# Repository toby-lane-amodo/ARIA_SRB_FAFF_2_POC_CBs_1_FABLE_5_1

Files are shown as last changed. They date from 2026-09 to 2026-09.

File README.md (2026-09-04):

# ARIA_SRB_FAFF_2_POC_CBs_1

Electronics for **FAFF 2** — a linear actuator with force feedback, built as an OEM-style
module for soft-material characterisation. `CBs_1` is the proof-of-concept control board.

A BLDC turns a 5 mm/rev ball screw. A load cell between the screw and an interchangeable probe
tip measures applied force; a magnetic linear encoder measures displacement directly. An
STM32H723 closes a force or displacement control loop and streams force and position to a host
over USB at up to 4800 SPS.

Two build variants, differing only in maximum force: **V50N** (± 50 N) and **V10N** (± 10 N).

> **This board is deliberately larger than the final product.** It is a development-board-style
> build that precedes miniaturisation, so that every block can be brought up and measured
> independently. See [`docs/TEST_PLAN.md`](docs/TEST_PLAN.md).

## Status

**Schematic complete and integrated**, first review pass applied. All nine blocks are drawn,
the root sheet is wired, and the design is internally consistent: 398 components, 251 nets,
101 sheet pins, **0 ERC errors and 0 warnings** at `--severity-all` with nothing suppressed.
Every component has a footprint that resolves.

Review the KiCad files themselves — there is no PDF and none is generated (`DEC-0028`).
The open points to be ruled on are in
[`hardware/kicad/faff2_cbs1/SCHEMATIC_REVIEW_LOG.md`](hardware/kicad/faff2_cbs1/SCHEMATIC_REVIEW_LOG.md),
round 1. **PCB layout is the next wave**; no board file exists yet.

## Repository map

```
README.md                        this file
AGENTS.md                        conventions every session needs
docs/
  REQUIREMENTS.md                numbered requirements, traceable to the spec, both variants
  ARCHITECTURE.md                block architecture, MCU resource allocation, open gaps
  DECISIONS.md                   every judgement call, dated, with reasoning
  TEST_PLAN.md                   test points, isolation, current breaks, bring-up order
  FAFF-2-Electronics-Full.svg    THE block diagram (authoritative architecture)
  HardwareDesignStandard_DRAFT/  captain's in-house EEE design standard (verbatim draft)
  decisions/                     one record per schematic task, incl. actuator-sch-integrate.md
  review/                        the schematic review pack PDF (regenerate, never hand-edit)
hardware/
  kicad/faff2_cbs1/              the KiCad 9 project - see below
  cubemx/                        the STM32CubeMX .ioc - THE MCU pin-map authority
tools/                           re-runnable generators for the root sheet and the DRV8323S land
datasheets/                      collected datasheets (see its README for the shopping list)
```

## The KiCad project

`hardware/kicad/faff2_cbs1/faff2_cbs1.kicad_pro` — **KiCad 9 only** (DEC-0017).

| Sheet | Block |
|---|---|
| `faff2_cbs1.kicad_sch` | root - the block map, wired: 101 sheet pins (DEC-0022) |
| `power_entry_24v.kicad_sch` | 24 V in on KPJX-4S, protection |
| `power_rails.kicad_sch` | 24 V → 5 V / 3V3 / analog rails |
| `mcu.kicad_sch` | STM32H723VET6, USB3320 ULPI PHY, USB-C, QSPI RAM |
| `motor_drive.kicad_sch` | DRV8323 + FETs, current sense, motor + encoder connectors |
| `loadcell_afe.kicad_sch` | ADS1235 bridge ADC, 5 V excitation |
| `linear_encoder.kicad_sch` | RS-422 receiver, Bogen IKP11 header |
| `temp_sense.kicad_sch` | ADS1120, two RTD/NTC probe channels |
| `nvm_calibration.kicad_sch` | I2C EEPROM for calibration data |
| `ui_io.kicad_sch` | buttons, LEDs, SMA SYNC out, limit switches |

The `mcu` sheet is **A2**; every other sheet is A3. There is no `test_debug` sheet — test
coverage lives on the circuit page it covers, so the SWD + USART3 debug header, the rail probe
header and the GND hooks are blocks H, J and K on `mcu`
([`docs/decisions/actuator-rev-testdebug.md`](docs/decisions/actuator-rev-testdebug.md)).

**One block per file, one owner per file.** See `AGENTS.md`.

### Setting up the Amodo library (required before opening the project)

The project's `sym-lib-table` and `fp-lib-table` reference the house library through path
variables. Set **both**, in KiCad → *Preferences* → *Configure Paths*:

| Variable | Windows (captain's KiCad) | WSL / Linux |
|---|---|---|
| `AMODO_KICAD_LIB` | `C:\Amodo\AmodoKiCadLib` | `/mnt/c/Amodo/AmodoKiCadLib` |
| `AMODO_3D` | `C:\Amodo\AmodoKiCadLib\3D` | `/mnt/c/Amodo/AmodoKiCadLib/3D` |

`AMODO_3D` is needed separately because the Amodo footprints already reference their 3D models
through it. Without these the symbols and footprints will not resolve. See DEC-0015.

### Checking the schematic

```sh
AMODO_KICAD_LIB=/mnt/c/Amodo/AmodoKiCadLib \
  kicad-cli sch erc --severity-all --exit-code-violations \
  -o /tmp/erc.rpt hardware/kicad/faff2_cbs1/faff2_cbs1.kicad_sch
```

Currently **0 errors, 0 warnings**, with no severity suppressed (DEC-0021). Keep it that way.

## Source documents

The project document store lives in Notion, at
**TERN - University of Cambridge / ARIA_SRB_FAFF_2 / ARIA_SRB_FAFF_2 Document Store**:

| Document | Role |
|---|---|
| *Project Specification Document* | **The requirements authority.** `docs/REQUIREMENTS.md` consolidates it; where they disagree, Notion wins |
| *ARIA_SRB_FAFF_2_CBs_1 Design Log* | Electronics decisions and part selection rationale |
| *ARIA_SRB_FAFF_2_CBs_1 Block Diagram* | Excalidraw source of `docs/FAFF-2-Electronics-Full.svg` |
| *ARIA_SRB_FAFF_2 Handover Document* | Project handover |
| Specification Design Log | How the spec numbers were derived |

Also referenced: the Google Sheet **FAFF 2 EEE Prelim Calc** (force/noise budget, BLDC sizing,
power budget) and **FAFF2 Plan and Budget** (work-package phasing).

## Key parts

STM32H723VET6 · DRV8323 gate driver · USB3320 ULPI PHY · TI ADS1235 bridge ADC · TI ADS1120
temperature ADC · HBK S2M load cell (10 N / 50 N) · Bogen IKP11 magnetic linear encoder ·
KPJX-4S power connector. BLDC deliberately not fixed (DEC-0004).

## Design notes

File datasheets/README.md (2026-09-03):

# Datasheets

Collect datasheets for the parts below as blocks are designed. Keep the manufacturer's own PDF
where possible, named `<MPN>.pdf`.

Note that KiCad symbols must carry a **working web URL** in their Datasheet field (pressing `d`
in KiCad opens it) — these local copies are for offline reference, not a substitute.

## Collected

| File | Part | Block | Revision |
|---|---|---|---|
| `250721_IKP11_technical_data_sheet.pdf` | Bogen IKP11 | `linear_encoder` | rev 3.7, 2025-07-21 (supersedes the rev linked below) |
| `LMR51610.pdf` | TI LMR51606/LMR51610 buck | `power_rails` | SLUSEY1B, Dec 2023 - added for the `U301` swap, review round 1 batch 2 |
| `ADPL42005.pdf` | ADI ADPL42005 LDO | `power_rails` | Rev. 0, 2024 - added for the `U302`/`U303` swap, review round 3. **Mirror copy** (datasheetall.com): analog.com times out from the build environment. Same Rev. 0 document; re-fetch from analog.com when a machine can reach it |

## Fixed parts

✅ = collected, see above.

| Part | Block | Notes |
|---|---|---|
| STM32H723VET6 | `mcu` | LQFP100. Datasheet + RM0468 reference manual. CPN `STM32H723VET6TR` |
| USB3320 | `mcu` | USB 2.0 ULPI transceiver |
| DRV8323 | `motor_drive` | 3-phase gate driver, SPI variant, 3 integrated current-sense amplifiers |
| TI ADS1235 | `loadcell_afe` | 24-bit bridge ADC. **Symbol already exists in `Amodo_ADCs.kicad_sym`** |
| TI ADS1120 | `temp_sense` | 16-bit ADC with PGA and IDACs, for RTD/NTC |
| HBK S2M | `loadcell_afe` | Load cell, 10 N and 50 N variants. Datasheet + wiring diagram (4- and 6-wire) |
| Bogen IKP11 ✅ | `linear_encoder` | `IKP11-Z1.4-P1-V5-D1-R0.5-F1000-C1`. Local: `250721_IKP11_technical_data_sheet.pdf` (rev 3.7). Web: [technical data sheet](https://www.bogen-magnetics.com/media/450/t-file/240802_IKP11_technical_data_sheet-1.pdf) — note that URL serves the older 2024-08-02 revision |
| Bogen LMS-I1-L70-W5-A03-K | (mechanical) | Magnetic scale, adhesive backed, ±3 µm accuracy class |
| KPJX-4S | `power_entry_24v` | Latching circular power connector, 4-way |

## To be selected

| Part | Block | Notes |
|---|---|---|
| QSPI RAM / memory | `mcu` | For force profiles, on OCTOSPI1 in quad mode |
| I2C EEPROM | `nvm_calibration` | Calibration and compensation data |
| Power FETs (×6) | `motor_drive` | 24 V, sized around 1.229 A phase working point |
| Rail regulators | `power_rails` | Set undecided — see OQ-02 |
| RS-422 receiver | `linear_encoder` | 3 channels (A/B/Z), 5 V in → 3V3 logic out |
| Temperature probes (×2) | `temp_sense` | RTD or NTC — see OQ-04 |
| USB-C receptacle, SMA jack | `mcu`, `ui_io` | |
| ESD protection devices | interfaces | USB-C, SMA, encoder, limit switch inputs |

## Explicitly NOT needed

**USB-PD / CYPD-class controllers.** FAFF 1 used a CYPD3177-class part; FAFF 2 has a dedicated
24 V supply and the USB-C port carries data only. Do not collect these. See DEC-0001, DEC-0002.

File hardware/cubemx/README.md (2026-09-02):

# CubeMX

`ARIA_SRB_FAFF_2_POC_CBs_1.ioc` is the STM32CubeMX starting point from the captain, and is
**the authority for the MCU part and every MCU-side pin assignment and net name** (DEC-0013).
Pin allocations are quoted in `docs/ARCHITECTURE.md §3.2` so you need not open CubeMX to
draw a block; if a block needs a pin that is not there, change the `.ioc` first and re-commit it.

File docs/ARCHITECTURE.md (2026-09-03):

# FAFF 2 CBs_1 - Electronics Architecture

The electronics block architecture for the `ARIA_SRB_FAFF_2` proof-of-concept control board,
as evidenced by the specification, the block diagram, the CBs_1 electronics design log, the
preliminary calculations, and the CubeMX starting point.

**Read `docs/REQUIREMENTS.md` first.** Requirement IDs (`REQ-*`) and decision IDs (`DEC-*`,
`OQ-*`) referenced here are defined there and in `docs/DECISIONS.md`.

## 1. Authorities

| Rank | Artefact | Authority over |
|---|---|---|
| 1 | Notion *Project Specification Document* | All requirements. |
| 2 | `docs/FAFF-2-Electronics-Full.svg` | Block-level architecture: which blocks exist and how they interconnect. |
| 3 | `hardware/cubemx/ARIA_SRB_FAFF_2_POC_CBs_1.ioc` | The MCU part and every MCU-side pin assignment and net name. |
| 4 | Notion *CBs_1 Design Log* | Part selections and their rationale. |
| 5 | `faff2-eee-prelim-calc.md` (Google Sheet extract) | The numbers behind the spec. |

The predecessor `ARIA_FAFF_CBs_1-block-diagram-v0.1.drawio` (FAFF 1) is **superseded** and is
reference only. FAFF 1 used a stepper motor, USB-PD power negotiation (CYPD3177-class), a
barrel-jack alternate input and a power-OR stage. **None of those are in FAFF 2** - see DEC-0001
and DEC-0002.

## 2. System context

A linear actuator for soft-material characterisation. A BLDC turns a 5 mm/rev ball screw; a
load cell between the screw and an interchangeable probe tip measures applied force; a magnetic
linear encoder measures displacement directly. The board closes a force or displacement control
loop and streams force and position to a host over USB.

Off-board, on the actuator (`BD`: "Linear Actuator Mech Parts"): the BLDC and its rotary
encoder/Hall sensors, the IKP11 read head and its magnetic scale, and the HBK S2M load cell.
Everything else is on CBs_1.

Control rates: ADC sampling 4800 SPS, closed-loop force bandwidth 40 Hz spec (48 Hz by the
calculation's 100:1 sample ratio), host stream decimated to 150 SPS. `REQ-ME-06`, `REQ-CC-03`.

## 3. Block architecture

```
                                                          [ off-board, on the actuator ]
  KPJX-4S 24 V ──▶ power_entry_24v ──▶ power_rails ──▶ (all blocks)
                         │ V24_MON            │
                         │                    │ +24V_SW
                         ▼                    ▼
                        mcu ◀──────────── motor_drive ──▶ J-MOT ─▶ BLDC
                   STM32H723VET6      DRV8323 + 6 FETs
                         │            phase I, VBUS, FET temp
                         │            ◀── J-MENC ── rotary encoder A/B/I + Halls
                         │
     ┌───────────────────┼────────────────────┬───────────────┬──────────────┐
     │ SPI3              │ TIM5               │ SPI2          │ I2C1         │ GPIO/TIM15
     ▼                   ▼                    ▼               ▼              ▼
 loadcell_afe      linear_encoder        temp_sense     nvm_calibration    ui_io
   ADS1235          RS-422 rx             ADS1120         EEPROM        buttons, LEDs,
     │                  │                     │                          SMA SYNC,
     ▼                  ▼                     ▼                          limit switches
  J-LC ─▶ S2M      J-ENC ─▶ IKP11      J-T1 (load cell)                       │
                                       J-T2 (encoder rail mid)                │ LIMIT_nBRK
                                                                              ▼
     mcu also carries: USB3320 ULPI PHY ──▶ USB-C (data only)          TIM1 BREAK
                       OCTOSPI1 quad ──▶ force-profile RAM             (motor kill)
                       SWD + USART3 ──▶ debug header (on the mcu sheet)
```

### 3.1 Block responsibilities

| Sheet file | Block | Responsibility | Chief evidence |
|---|---|---|---|
| `power_entry_24v.kicad_sch` | Power entry | 24 V in on KPJX-4S; protection, fusing, inrush, TVS, filtering; `V24_MON` divider | REQ-EL-01..04 |
| `power_rails.kicad_sch` | Power rails | +24V_SW → +5V, +3V3, analog rail(s) + reference; per-rail isolation links and current breaks | REQ-EL-02/03, CALC power budget |
| `mcu.kicad_sch` | Controller | STM32H723VET6, clocks, reset, boot, SWD; USB3320 ULPI PHY + USB-C; OCTOSPI1 quad RAM | REQ-AR-01/12/13/16 |
| `motor_drive.kicad_sch` | Motor drive | DRV8323 + 6 FETs, phase current sense, DC-link sense, FET temp, motor + rotary-encoder connectors | REQ-AR-02..06 |
| `loadcell_afe.kicad_sch` | Load cell AFE | ADS1235 bridge ADC, 5 V excitation, 4-/6-wire load cell interface | REQ-FF-08..13, REQ-AR-08/09 |
| `linear_encoder.kicad_sch` | Linear encoder | RS-422 A/B/Z receiver → 3V3, IKP11 header, 5 V read-head supply | REQ-PS-05..09, REQ-AR-07 |
| `temp_sense.kicad_sch` | Temperature | ADS1120 + two RTD/NTC probe channels | REQ-EL-07, REQ-AR-10 |
| `nvm_calibration.kicad_sch` | NVM | I2C1 EEPROM for calibration and compensation data | REQ-EL-08, REQ-AR-11 |
| `ui_io.kicad_sch` | User I/O | Buttons, LEDs, SMA SYNC out, limit switch inputs incl. the hardware brake path | REQ-EL-05/06/09, REQ-CC-06, REQ-SF-01/05 |

Nine sheets, not ten. **Test coverage lives on the circuit page it covers**, so there is no
`test_debug` sheet: the SWD + USART3 debug header (`REQ-AR-15`), the consolidated rail probe
header and the GND hooks for scope clips are blocks **H**, **J** and **K** on `mcu.kicad_sch`,
alongside the crystal that gives the USB PHY its own 24 MHz reference (block **C**).
See `docs/decisions/actuator-rev-testdebug.md`.

### 3.2 MCU resource allocation

From the `.ioc` — the authority. Quoted here so block workers need not open CubeMX.

**Motor drive (TIM1, ADC1/2, SPI2)**
| Net | Pin | Function |
|---|---|---|
| `MOTOR_PWM_AH/AL` | PE9 / PE8 | TIM1_CH1 / CH1N |
| `MOTOR_PWM_BH/BL` | PE11 / PE10 | TIM1_CH2 / CH2N |
| `MOTOR_PWM_CH/CL` | PE13 / PE12 | TIM1_CH3 / CH3N |
| `DRV8323_nFAULT` | PE15 | TIM1_BKIN - hardware trip |
| `LIMIT_nBRK` | PE6 | TIM1_BKIN2 - hardware trip |
| `MOTOR_I_A/B/C` | PA6 / PC4 / PA7 | ADC INP3 / INP4 / INP7 |
| `MOTOR_FETTEMP` | PA4 | ADC INP18 |
| `VBUS_MON` | PC5 | ADC INP8 (see OQ-01) |
| `DRV8323_EN/CAL/nCS` | PD10 / PD5 / PD7 | GPIO out |
| `MOTOR_ENCODER_A/B/I` | PC6 / PC7 / PC8 | TIM3 CH1 / CH2 / CH3 |
| `HALL1/2/3` | PE14 / PD14 / PD15 | GPIO in |

**Load cell AFE (SPI3)**
| Net | Pin | Function |
|---|---|---|
| `ADS1235_SCLK/MISO/MOSI` | PC10 / PC11 / PD6 | SPI3 |
| `ADS1235_nCS` | PA15 | SPI3_NSS (hardware NSS) |
| `ADS1235_nDRDY` | PD1 | EXTI1 |
| `ADS1235_START` | PC12 | GPIO out |
| `ADS1235_nRESET` | PD0 | GPIO out |
| `ADS1235_CLKIN` | PC9 | RCC_MCO2 - ADC master clock |

**Linear encoder (TIM5)**: `LINEAR_ENCODER_A/B/Z` = PA0 / PA1 / PA2. TIM5 encoder mode TI12 on
A/B; CH3 input capture on Z.

**Shared config bus (SPI2, "CONFIG_SPI")**: `CONFIG_SPI_SCK` PA9, `CONFIG_SPI_MISO` PB14,
`CONFIG_SPI_MOSI` PB15. Chip selects: `DRV8323_nCS` PD7, `ADS1120_nCS` PD3.
**Three blocks share this bus** - see §5.

**NVM (I2C1)**: `EEPROM_SCL` PB8, `EEPROM_SDA` PB9.

**Force-profile RAM (OCTOSPI1, quad)**: `QSPI_P1_CLK` PB2, `QSPI_P1_nCS` PB6,
`QSPI_P1_IO0..IO3` PD11 / PD12 / PE2 / PD13.

**USB (USB_OTG_HS, ULPI, device HS)**: `ULPI_D0..D7` = PA3, PB0, PB1, PB10, PB11, PB12, PB13,
PB5; `ULPI_CK` PA5; `ULPI_STP` PC0; `ULPI_DIR` PC2_C; `ULPI_NXT` PC3_C;
`USB3320_nRESET` PE4.

**User I/O**: `BTN_1/2` PE0 / PE1; `LED_1/2` PA12 / PA11; `SYNC_TRIG` PE5 (TIM15_CH1);
`LIM_A` PD2 (EXTI2), `LIM_B` PD4 (EXTI4).

**Debug**: SWDIO PA13, SWCLK PA14, SWO PB3; `DBG_TX` PD8, `DBG_RX` PD9 (USART3).

**Clock**: `PH0-OSC_IN` in *HSE external clock source* mode. `PH1-OSC_OUT` is **not**
allocated, so the HSE input must be a driven clock, not a bare crystal (OQ-03). CubeMX
currently shows PLL source HSI and SYSCLK 64 MHz - that is the untouched CubeMX default, not a
designed clock tree, and it will change.

77 of 100 pins are allocated. Spare pins exist for the gaps in §6.

## 4. Power architecture

24 V enters on the KPJX-4S latching circular connector (REQ-EL-04). There is **no USB-PD, no
bus power and no alternate barrel-jack input** - all three were FAFF 1 features (DEC-0001,
DEC-0002). USB-C carries USB 2.0 data only.

Budget: 5.185 W quiescent, 25 W peak (REQ-EL-03), 7 W typical at a static 50 N hold
(REQ-EL-02). The 5 V rail feeds bridge excitation and the IKP11 read head; 3V3 feeds the MCU,
USB3320, DRV8323 logic, QSPI and EEPROM; the ADS1235 and ADS1120 need a quiet analog rail and
reference.

**Awaiting evidence.** The block diagram is signal-architecture only and shows **no power
blocks at all**. Rail count, topology (switcher vs LDO), sequencing and the analog-rail
strategy are therefore **not** externally specified - they are OQ-02, to be decided by the
`power_rails` task and recorded in `DECISIONS.md`.

## 5. Cross-block concerns

Things no single block owns. A block worker who changes one of these must say so.

1. **SPI2 is shared** by `motor_drive` (DRV8323), `temp_sense` (ADS1120) and, by proximity,
   any future config peripheral. Bus loading, series termination and the stub topology are a
   joint concern. Chip selects are per-peripheral, so only the three bus wires are shared.
2. **The TIM1 BREAK path is safety-critical.** Two independent sources trip it: `DRV8323_nFAULT`
   (PE15, BKIN) from `motor_drive`, and `LIMIT_nBRK` (PE6, BKIN2) from `ui_io`. Neither block
   may change the polarity or the drive type of its break net unilaterally. REQ-SF-05/06.
3. **Analog ground and reference strategy** spans `power_rails`, `loadcell_afe` and
   `temp_sense`. The 40 nV-scale signals of the load cell path (SLOG) set the bar.
4. **Motor FET temperature** (`MOTOR_FETTEMP`, PA4, internal ADC) belongs to `motor_drive`, not
   to `temp_sense`. `temp_sense` owns only the two ADS1120 precision channels of REQ-EL-07.
   DEC-0011.
5. **Test points and isolation links** follow the producer-owns-the-break rule: whichever block
   generates a rail or signal owns its test point, isolation link and current break. DEC-0007.

## 6. What is still awaiting evidence

Facts this architecture does **not** yet fix, and what would fix them.

| Gap | Blocked on | Tracked as |
|---|---|---|
| Rail set, topology, sequencing, analog-rail strategy | Block diagram is signal-only; needs a design decision | OQ-02 |
| HSE external clock source | `mcu` task decision, possibly shared with USB3320 | OQ-03 |
| `VBUS_MON` allocation (motor DC-link vs USB VBUS) | Captain confirmation | OQ-01 |
| Temperature probe type (RTD vs NTC) | `temp_sense` task decision | OQ-04 |
| EEPROM `nWP`, rail PGOOD/enable pins | No `.ioc` pins allocated; may need an `.ioc` revision | OQ-06, OQ-07 |
| Per-variant current-limit implementation | `motor_drive` task decision | OQ-08 |
| Root-sheet interconnect wiring | Child sheets must declare hierarchical labels first | DEC-0009 |
| BLDC part number | Deliberately open - all candidates share this design | DEC-0004 |
| Load cell 4-wire vs 6-wire build | Support both; 6-wire is the accuracy option | DEC-0014 |

## 7. Superseded FAFF 1 features

For reviewers who know the predecessor. Do not carry these across.

| FAFF 1 | FAFF 2 | Why |
|---|---|---|
| Stepper motor drive | BLDC, DRV8323 + FETs | Stepper resonances and gearbox poles; BLDC pole separation pushes resonances far higher (SLOG) |
| USB-PD controller (CYPD3177-class) | None | Dedicated 24 V supply; USB is data only (REQ-EL-10) |
| Barrel jack alternate input + power OR | Single KPJX-4S 24 V input | REQ-EL-04 |
| STM32H7 (unspecified) | STM32H723VET6, pinned | `.ioc` (DEC-0013) |
| Renishaw ATOM DX linear encoder | Bogen IKP11, RS-422 | 34-week ATOM DX lead time (DEC-0003) |

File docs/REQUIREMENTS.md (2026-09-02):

# FAFF 2 CBs_1 - Consolidated Requirements

Consolidated, numbered requirements for the **ARIA_SRB_FAFF_2** proof-of-concept control
board (`CBs_1`). Every requirement traces to a source; values are quoted verbatim from the
source, including both design variants.

**Authority.** The Notion *Project Specification Document* is the requirements authority.
Where this file and Notion disagree, Notion wins and this file is a defect.

| Tag | Source |
|---|---|
| `SPEC` | Notion, *ARIA_SRB_FAFF_2 Document Store / Project Specification Document* |
| `ELOG` | Notion, *ARIA_SRB_FAFF_2_CBs_1 Design Log* |
| `SLOG` | Notion, *Specification Design Log* |
| `CALC` | Google Sheet *FAFF 2 EEE Prelim Calc* (extract `faff2-eee-prelim-calc.md`) |
| `BD` | `docs/FAFF-2-Electronics-Full.svg` - FAFF 2 electronics block diagram |
| `IOC`  | `hardware/cubemx/ARIA_SRB_FAFF_2_POC_CBs_1.ioc` - STM32 pin-map authority |

**Variants.** Two build variants differing only in maximum force: **V50N** (± 50 N) and
**V10N** (± 10 N). `SPEC §2.3`.

Status key: **B** = binding on CBs_1 electronics; **C** = context (mechanical/firmware, drives
electronics indirectly); **O** = open, see [Open Questions](#open-questions).

---

## 1. Mechanical context (`REQ-ME-*`)

Not electronics deliverables, but they set the electrical operating point.

| ID | Requirement | V50N | V10N | Unit | Source | St |
|---|---|---|---|---|---|---|
| REQ-ME-01 | Displacement range | 40 | 40 | mm | SPEC §3 | C |
| REQ-ME-02 | Continuous force | ± 50 | ± 10 | N | SPEC §3 | C |
| REQ-ME-03 | Maximum actuation speed | 20 | 20 | mm/s | SPEC §3 | C |
| REQ-ME-04 | Max cycle speed (low), force control | 10 | 10 | cycles/min | SPEC §3 | C |
| REQ-ME-05 | Max cycle speed (fast), force control | 60 | 60 | cycles/min | SPEC §3 | C |
| REQ-ME-06 | Force control loop bandwidth (small signal) | 40 | 40 | Hz | SPEC §3 | B |
| REQ-ME-07 | Probe tip interchangeable, threaded socket | — | — | — | SPEC §3 | C |
| REQ-ME-08 | Ball screw lead | 5 | 5 | mm/rev | SPEC assumptions, CALC | C |

Notes on REQ-ME-04/05: 1 % max force over/undershoot (% of commanded step amplitude),
amplitude < 4 mm pk-pk at 10 cyc/min; 5 % and amplitude < 6 mm pk-pk at 60 cyc/min. `SPEC §3`.

## 2. Force feedback (`REQ-FF-*`)

| ID | Requirement | V50N | V10N | Unit | Source | St |
|---|---|---|---|---|---|---|
| REQ-FF-01 | Sensing method: load cell | Load cell | Load cell | — | SPEC §4 | B |
| REQ-FF-02 | Force measurement range | ± 50 | ± 10 | N | SPEC §4 | B |
| REQ-FF-03 | Force accuracy | 60 | 12 | mN | SPEC §4 | B |
| REQ-FF-04 | Force noise, 4800 SPS raw | < 20 | < 5 | mN pk-pk | SPEC §4 | B |
| REQ-FF-05 | Force noise, 150 SPS decimated | < 2.5 | < 0.5 | mN pk-pk | SPEC §4 | B |
| REQ-FF-06 | Force resolution, 4800 SPS raw | 2 | 0.5 | mN | SPEC §4 | B |
| REQ-FF-07 | Force resolution, 150 SPS decimated | 1 | 0.2 | mN | SPEC §4 | B |
| REQ-FF-08 | Load cell: HBK S2M, accuracy class 0.02 | — | — | — | SPEC assumptions, SLOG | B |
| REQ-FF-09 | Load cell sensitivity | 2 | 2 | mV/V | SPEC §"Force" | B |
| REQ-FF-10 | Bridge excitation voltage | 5 | 5 | V | SPEC §"Force" | B |
| REQ-FF-11 | Full-scale bridge output swing | ± 10 | ± 10 | mV | SPEC §"Force" | B |
| REQ-FF-12 | Bridge ADC: ADS1235, gain 128, 4800 SPS Sinc2 | — | — | — | CALC, ELOG, BD | B |
| REQ-FF-13 | Load cell connection: 4-wire **or** 6-wire | — | — | — | BD ("4 or 6 wire") | B |

REQ-FF-03 note (SPEC §4): "All stream rates. Dominated by load cell systematics. Averaging
does not improve accuracy. Accuracy valid at 20 ± 2 °C."

Supporting calculation (`CALC`, Force sheet), for traceability only - not itself a requirement:
input sensitivity 0.2 mV/N (V50N) / 1.0 mV/N (V10N); ADS1235 input noise 2.40 µV pk-pk at
4800 SPS Sinc2 = 12.0 / 2.4 mN pk-pk, giving 167 % / 208 % headroom against REQ-FF-04.
ADS1235 FSR 78.125 mV at gain 128 / VREF 5 V; 18-bit conservative depth gives 1.49 / 0.30 mN
ADC resolution (134 % / 168 % headroom against REQ-FF-06). Streamed output 150 SPS,
2.12 / 0.42 mN pk-pk against the 2.5 / 0.5 mN of REQ-FF-05.

## 3. Position sensing (`REQ-PS-*`)

Single specification, both variants. `SPEC §5`.

| ID | Requirement | Value | Unit | Source | St |
|---|---|---|---|---|---|
| REQ-PS-01 | Position resolution | 1 | µm | SPEC §5 | B |
| REQ-PS-02 | Position accuracy | ± 5 | µm | SPEC §5 | B |
| REQ-PS-03 | Repeatability | ± 1 | µm | SPEC §5 | B |
| REQ-PS-04 | Sensing method: optical or magnetic linear encoder | — | — | SPEC §5 | B |
| REQ-PS-05 | Linear encoder: Bogen IKP11-Z1.4-P1-V5-D1-R0.5-F1000-C1 | — | — | ELOG, BD | B |
| REQ-PS-06 | Encoder interface: RS-422 differential A/B/Z, receive to 3V3 logic | — | — | ELOG, BD, IOC | B |
| REQ-PS-07 | Encoder resolution 0.5 µm; max output 1 MHz per channel | — | — | ELOG | B |
| REQ-PS-08 | Encoder supply | 5 | V | ELOG (IKP11 "V5") | B |
| REQ-PS-09 | Encoder connector: 10-way 1.27 mm header (IKP11 "C1") | — | — | ELOG | B |
| REQ-PS-10 | Incremental encoder implies a power-on homing routine | — | — | SPEC §6, ELOG | B |

REQ-PS-05 supersedes the Renishaw ATOM DX of `SPEC` assumptions and `SLOG`: rejected on a
34-week lead time. See DEC-0003.

## 4. Electrical and electronics (`REQ-EL-*`)

Single specification, both variants. `SPEC §6`.

| ID | Requirement | Value | Unit | Source | St |
|---|---|---|---|---|---|
| REQ-EL-01 | Supply voltage | 24 | V | SPEC §6 | B |
| REQ-EL-02 | Typical power consumption (static 50 N hold) | 7 | W | SPEC §6 | B |
| REQ-EL-03 | Peak power consumption | 25 | W | SPEC §6 | B |
| REQ-EL-04 | Power connector: KPJX-4S latching circular | — | — | SPEC §6 | B |
| REQ-EL-05 | SYNC/TRIGGER: 3.3 V push-pull output, 50 Ω source terminated | — | — | SPEC §6 | B |
| REQ-EL-06 | SYNC/TRIGGER connector: SMA jack | — | — | SPEC §6 | B |
| REQ-EL-07 | Temperature measured to 1 °C at (a) the load cell and (b) the mid-point of the linear encoder measurement rail, for compensation | 1 | °C | SPEC §6 | B |
| REQ-EL-08 | Non-volatile storage for calibration and compensation data | — | — | SPEC §6 | B |
| REQ-EL-09 | Limit switches may be used for a power-on homing routine | — | — | SPEC §6 | B |
| REQ-EL-10 | Data connector: USB-C. **This port will not power the hardware.** | — | — | SPEC §6 | B |

Power budget (`CALC`, Power Budget sheet), traceability only: quiescent total **5.185 W** -
STM32 3.3 V / 0.5 A, linear encoder 5 V / 0.2 A, BLDC rotary encoder 3.3 V / 0.1 A, load cell
5 V / 15 mA, other ICs 3.3 V / 0.5 A, motor Iq 24 V / 20 mA. Motor at 50 N static: 1.229 A
phase, 0.951 W loss (driver losses neglected).

## 5. Control and communications (`REQ-CC-*`)

| ID | Requirement | Source | St |
|---|---|---|---|
| REQ-CC-01 | Operational modes: dynamic force, dynamic displacement, static force, static displacement | SPEC §7.1 | C |
| REQ-CC-02 | Device presents a USB 2.0 interface | SPEC §7.2 | B |
| REQ-CC-03 | Force and linear position streamed at up to 4800 samples per second | SPEC §7.2 | B |
| REQ-CC-04 | Device functions and data accessible via an API; any GUI uses that API | SPEC §7.2 | C |
| REQ-CC-05 | Streamable data: measured force, measured linear position | SPEC §7.2 | C |
| REQ-CC-06 | Homing routine initiated via API **or an external button** | SPEC §7.2 | B |

## 6. Environmental (`REQ-EN-*`)

| ID | Requirement | Value | Unit | Source | St |
|---|---|---|---|---|---|
| REQ-EN-01 | Operating temperature | 10 to 40 | °C | SPEC §8 | B |
| REQ-EN-02 | Storage temperature | 0 to 50 | °C | SPEC §8 | B |
| REQ-EN-03 | Humidity, non-condensing | 20 to 80 | % RH | SPEC §8 | B |

## 7. Safety (`REQ-SF-*`)

| ID | Requirement | Source | St |
|---|---|---|---|
| REQ-SF-01 | End(s) of stroke to be limit switched | SPEC §9.1 | B |
| REQ-SF-02 | Firmware to kill motor drive on limit switch actuation | SPEC §9.1 | B |
| REQ-SF-03 | Peak motor current sense limit, preventing the actuator overloading 150 % of the load cell absolute maximum. **Must be configurable per variant.** | SPEC §9.1 | B |
| REQ-SF-04 | Consider a mechanical overload stop | SPEC §9.1 | C |
| REQ-SF-05 | Hardware limit-switch trip into TIM1 BREAK, in addition to REQ-SF-02 | BD, IOC (`LIMIT_nBRK` PE6 → TIM1_BKIN2), DEC-0012 | B |
| REQ-SF-06 | Gate-driver fault trip into TIM1 BREAK | BD ("BRK input on nFAULT"), IOC (`DRV8323_nFAULT` PE15 → TIM1_BKIN) | B |

REQ-SF-05/06 are architectural additions evidenced by the block diagram and `.ioc`; they
strengthen REQ-SF-02 rather than replacing it. See DEC-0012.

## 8. Standards and compliance (`REQ-SC-*`)

| ID | Requirement | Source | St |
|---|---|---|---|
| REQ-SC-01 | Prototype only: designed to EMC best practice, **no formal EMC testing**, **no CE mark** affixed | SPEC §10 | B |

## 9. Architecture requirements derived from the block diagram and `.ioc` (`REQ-AR-*`)

These are not in `SPEC`; they are the agreed implementation of it. They are binding on the
CBs_1 design because the block diagram is the authoritative architecture.

| ID | Requirement | Source | St |
|---|---|---|---|
| REQ-AR-01 | Controller: STM32H723VET6 (LQFP100, CPN STM32H723VET6TR) | IOC, BD | B |
| REQ-AR-02 | Motor drive: DRV8323 gate driver + discrete FETs driving a 3-phase BLDC | BD, IOC | B |
| REQ-AR-03 | Motor PWM from TIM1 (3 complementary channels, break enabled) | BD, IOC | B |
| REQ-AR-04 | Phase current and DC-link (VBUS) sense into ADC1/ADC2, dual injected-simultaneous mode | BD, IOC | B |
| REQ-AR-05 | Gate driver configuration over SPI2 ("Config") | BD, IOC | B |
| REQ-AR-06 | Motor rotary encoder A/B/Z into TIM3 (encoder mode + ch3 direct); Hall sensors on GPIO | BD, IOC | B |
| REQ-AR-07 | Linear encoder A/B/Z into TIM5 (encoder mode + ch3 direct) after RS-422 → 3V3 conversion | BD, IOC | B |
| REQ-AR-08 | ADS1235 on SPI3, config + data, with nDRDY interrupt | BD, IOC | B |
| REQ-AR-09 | ADS1235 data/master clock from STM32 MCO2 | BD, IOC | B |
| REQ-AR-10 | Temperature: ADS1120 ADC, RTD or NTC probes, on SPI2 | BD, IOC | B |
| REQ-AR-11 | Calibration data in an I2C1 EEPROM | BD, IOC | B |
| REQ-AR-12 | Force-profile RAM on OCTOSPI1 in quad (QSPI) mode | BD, IOC | B |
| REQ-AR-13 | USB-C → USB3320 ULPI PHY → USB_OTG_HS (device, high speed) | BD, IOC | B |
| REQ-AR-14 | Trigger output generated by TIM15 → SMA | BD, IOC | B |
| REQ-AR-15 | Debug header carrying USART3 UART **and** SWD | BD, IOC | B |
| REQ-AR-16 | HSE from an external clock source on PH0-OSC_IN only (PH1-OSC_OUT unallocated) | IOC | B |
| REQ-AR-17 | PoC build is a larger, development-board-style board preceding miniaturisation | SLOG, plan summary | B |

## Open questions

Tracked here, resolved into `DECISIONS.md` when answered.

| ID | Question | Why it matters | Owner |
|---|---|---|---|
| OQ-01 | Is `VBUS_MON` (PC5) the motor DC-link or USB VBUS presence? Provisionally allocated to the motor DC-link - see DEC-0011. | Decides whether the divider lives in `motor_drive` or `mcu`. | Captain |
| OQ-02 | Exact rail set and topology (5 V / 3V3 / analog): switcher vs LDO per rail, and whether the ADS1235/ADS1120 analog rail is separately regulated. | Sets the `power_rails` block contents; not covered by the block diagram, which is signal-only. | `power_rails` task |
| OQ-03 | Source of the HSE external clock on PH0-OSC_IN. Candidate: share one oscillator with the USB3320 (which needs a 24 MHz reference). | A single-pin external clock cannot be a bare crystal; needs a real oscillator or a driven clock. | `mcu` task |
| OQ-04 | Probe type for the two temperature channels: RTD or NTC (the block diagram permits both). | Sets ADS1120 excitation and the probe connectors. | `temp_sense` task |
| OQ-05 | Which of BTN_1 (PE0) / BTN_2 (PE1) is the REQ-CC-06 homing button, and what the other does. | Silkscreen and firmware contract only; not blocking. | Captain / firmware |
| OQ-06 | EEPROM write-protect (`nWP`) has no `.ioc` pin allocated. Tie off, or request a pin? | Affects `nvm_calibration` and may need an `.ioc` revision. | `nvm_calibration` task |
| OQ-07 | Rail PGOOD / enable lines have no `.ioc` pins allocated. | Same as OQ-06, for `power_rails`. | `power_rails` task |
| OQ-08 | Whether V10N needs a different current-sense shunt/gain to satisfy REQ-SF-03 "configurable per variant", or whether one shunt with a firmware threshold suffices. | Decides if `motor_drive` needs a build variant. | `motor_drive` task |

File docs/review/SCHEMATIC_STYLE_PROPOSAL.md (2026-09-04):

# Proposal: style rules to fold into `schematic-style`

**Status: proposal only. The `schematic-style` skill has not been touched.** The standing rule is
that the skill changes only with the captain's explicit approval, so this document exists to be
evaluated, edited and accepted or rejected item by item.

Everything here was established by the captain across schematic review rounds 1–4 and the
verification round on **FAFF 2 `CBs_1`**, but only rules that generalise beyond that board are
listed. Part selections, rail voltages, pin allocations and other FAFF-2 engineering decisions
are deliberately excluded — they live in `docs/DECISIONS.md` and the per-block decision files.

Each item gives:

* **Rule** — the text as it would appear in the skill: terse, imperative, checkable.
* **Origin** — where it came from. *Reference only: origins are not pushed to the skill.*
* **Status** — against the *current* skill text: **NEW**, **REFINES** (naming the rule),
  or **CONTRADICTS** (naming the rule and showing both).
* **Disposition** — the ruling, and what to do with the item.

## How to apply this document

This is the spec for the skill update. Four rules govern it:

1. **Only the Rule text goes into the skill.** Origins do not: where a rule came from is not
   relevant to someone reading the skill.
2. **A refinement is folded into the existing skill line as added detail — not added as a new
   line or a new attribute.** Where an item's Status names an existing rule, extend that rule;
   do not create a second bullet saying something adjacent.
3. **Plain designer-to-designer style throughout.** No process narration, no roles, no review
   rounds, no project names. A rule reads as an instruction to the next engineer.
4. **Anything not commented on is approved as written.**

Every item is ruled on; nothing is held.

---

## A. Placement and wiring

### 1. Four-way junctions — the ERC will not catch them

**Rule.** Never join four wires at one point. KiCad's `four_way_junction` ERC rule **defaults to
`ignore`**, so a clean ERC is not evidence: check geometrically, by counting wire endpoints that
coincide with each junction.

**Origin.** *"Never ever use a 4-way net connection."*

**Status.** **REFINES** *"Wire crossings are acceptable in moderation; 4-way junctions never."*
The prohibition is already there; what is missing is that the automated check is off by default,
which is how one survives a 0/0 ERC.

**Disposition.** **APPROVED** — as written. Fold into the named rule as added detail; do not add a new bullet.

### 2. Series elements lie along the flow

**Rule.** Place series elements — 0 Ω links, ferrite beads, series terminators, current-sense
elements — **horizontally**, in line with the left-to-right flow of the net they sit in, so power
and signal run in one direction without unnecessary corners.

**Origin.** *"Series output zero ohm links for regulators should be placed horizontally, not
vertically."* and *"Ferrite beads used for rail filtering should be placed horizontally … to keep
flow of power in one direction, without un-necessary corners."*

**Status.** **REFINES** *"No unnecessary bends: place parts so connected pin rows align and wires
run straight."* The existing rule is about wires; this one says which way the *part* goes, and
names the classes that are always in-line.

**Disposition.** **APPROVED** — as written. Fold into the named rule as added detail; do not add a new bullet.

### 3. Parallel elements stand vertically, matching their neighbours

**Rule.** A part in parallel with a column of others is drawn like them — same orientation, same
body height. A diode across a decoupling capacitor is vertical because the capacitors are.

**Origin.** *"D201 is in parallel with C204, etc, so graphically it should also be placed
vertically like C204 etc. Same for D202."*

**Status.** **REFINES** *"Paired elements align (e.g. two I2C pull-ups side by side at the same
height, supply flags level)."* Extends alignment from *pairs of the same part* to *anything in
parallel across the same net*, including mixed part types.

**Disposition.** **APPROVED** — as written. Fold into the named rule as added detail; do not add a new bullet.

### 4. Parallel parts share one ground-flag height

**Rule.** Every part in a parallel row puts its GND flag at the **same y**. Four flags on four
heights draws as a staircase. Where a row already agrees, the odd one out joins it; otherwise the
right height is the one that makes the bottom stub match the top stub. A local fix that solves a
collision by dropping one flag out of its row is not a fix.

**Origin.** *"It would be nice if GND connections for parallel components are vertically aligned.
R206 and C207 GND flags should be at the same vertical height."*, escalated in round 4 to
*"Parallel components share ONE GND-flag height — sweep ALL sets of parallel capacitors and
parallel parts across the design"*, with `C1113` named as the good case and `C1101`/`C1102` as the
bad one.

**Status.** **REFINES** the same *"Paired elements align … supply flags level"* clause. What is new
is that it is a **design-wide sweep**, not a local nicety, and that it overrides local collision
fixes. Worth pairing with a detector: group two-terminal parts by upper net and body y, split into
visual runs, and report any run whose flags disagree. Keep the thresholds in the tool rather than
in prose — what counts as "one row" is a judgement the tool encodes, not a number to memorise.

**Disposition.** **APPROVED** — as written. Fold into the named rule as added detail; do not add a new bullet. The row-detection thresholds stay in the tool, not in the skill text.

### 5. Potential dividers stack vertically

**Rule.** Draw a potential divider as one vertical column: top resistor, tap, bottom resistor,
ground, all on the same x.

**Origin.** *"Where you have a potential divider … make sure they are vertically aligned."*

**Status.** **NEW.** The skill covers even spacing and alignment of two-terminal parts but says
nothing about the divider as a shape.

**Disposition.** **APPROVED** — as written.

### 6. Power LEDs are vertical

**Rule.** Power-indicator LEDs and their series resistors are drawn vertically, in a column from
the rail to ground.

**Origin.** *"Power LEDs should also ideally be placed vertically."*

**Status.** **NEW.**

**Disposition.** **APPROVED** — as written.

### 7. Connectors face their wiring

**Rule.** Mirror or rotate a connector so its pins emerge on the side its wires leave towards.
Wires must never have to route around a connector body to reach the circuit.

**Origin.** *"Mirror the input power connector so that the pins come out left to right, and wires
don't have to route around its body."*

**Status.** **NEW**, and it interacts with the symbol rule below — see item 22. Note the mechanical
trap that comes with it: on a `(mirror y)` symbol, `(justify left)` renders text **leftward**, so a
mirrored connector's reference and value can run off the page while the file still reads as
left-justified.

**Disposition.** **APPROVED** — as written.

### 8. GND symbols always point down, and are never mirrored

**Rule.** A ground symbol points down. Never rotate one, never mirror one, and never make a
pre-rotated or mirrored ground variant. Where a dense pin row leaves no vertical room for one
ground per pin, stub every ground pin to a single vertical rail and terminate that rail in **one**
downward GND below the block; split the rail at every stub so each landing is a real tee.

**Origin.** *"GND connections are upside down. You must never ever do this."*

**Status.** **REFINES** *"GND symbols always face down — never rotate a ground, and never make a
pre-rotated ground variant."* The addition is the explicit word **mirrored**: a mirrored ground
draws identically to an unmirrored one in some orientations, so "never rotate" does not cover it.

**Disposition.** **APPROVED** — as written. Fold into the named rule as added detail; do not add a new bullet.

### 9. A body never straddles a wire, and a power symbol's arrow never grazes one

**Rule.** No component body may sit across a wire. Extend this to power symbols: a GND arrow's tip
or a rail arrow's tip touching a wire it does not connect to reads as a connection and is a defect,
even at zero overlap depth. Check by requiring the wire to run inside the body's outline for a real
distance (≳0.6 mm) rather than by looking for area overlap, and excuse only wires that land on that
symbol's own pins.

**Origin.** Round 3, from the captain's screenshots of `power_rails`; nine further instances were
then found design-wide by the same test.

**Status.** **REFINES** *"a component body must never straddle a wire."* The existing rule is
stated for component bodies; the failure in practice is power-symbol arrows, whose bounding boxes
are mostly empty triangle, so an area test finds nothing and a clearance test finds false hits
everywhere.

**Disposition.** **APPROVED** — as written. Fold into the named rule as added detail; do not add a new bullet.

---

## B. Text, labels and clearance

### 10. Power-symbol net names: one placement, everywhere

**Rule.** A power symbol's net name sits **directly above or below the symbol, centred on it, with
no sideways offset, close** — above a rail arrow, below a ground (the mirror is deliberate: "above"
a ground is where its wire arrives). The label is **pinned**: where it collides, move the *symbol*
along its own stub, move the neighbouring part or note, or grow the block box — never nudge the
label sideways to dodge.

**Origin.** *"Power labels are missing on most of the power flags on the design"*, then the round-2
ruling fixing the placement.

**Status.** **REFINES** *"power nets use power symbols with their text always visible."* Visibility
is in the skill; the placement discipline, and above all the "the label does not move, the world
moves" rule, are not.

**Disposition.** **APPROVED** — as written. Fold into the named rule as added detail; do not add a new bullet.

### 11. Sheet entry and exit flags read back over their own wire, in clean columns

**Rule.** Hierarchical labels at a sheet or block boundary are right-justified and read back over
the wire they name, aligned in a column. Text may lie over its **own** net — that is what "the wire
must extend under the entire label" requires — but never over a foreign wire, a body or another
label. Do not mix justifications within a column.

**Origin.** *"Same as other sheet review for sheet entry / exit labels justification. This text
should not overlap the wires."*, and round 4's `VBUS_MON`, which was the only label on its sheet
with the opposite justification.

**Status.** **REFINES** *"Net labels sit over their wire … At a wire end, anchor the label there
right-justified (angle 180 + justify right bottom) so the text reads back over the wire."*
**It also resolves an ambiguity that reads as a contradiction.** Taken literally, "this text should
not overlap the wires" forbids what the skill requires. The reconciliation is *electrical*: text
over its own **node** — the wire it labels and every branch of that node — is correct; text over
any other conductor is a defect. A checker needs the node, not just the one segment under the
anchor, or every branch dropping off a labelled wire reports as an overlap.

**Disposition.** **APPROVED** — as written. Fold into the named rule as added detail; do not add a new bullet.

### 12. Text clearance is measured against wires, borders, bodies and other text

**Rule.** Sweep text against **every** neighbour class: wires, block-box borders, symbol outlines
including the field's own symbol, notes, net labels, and other fields. Require real **clearance**,
not merely the absence of overlap — once both stroke widths are drawn, text a few tenths of a
millimetre off a wire reads as touching. Calibrate the margin to the library in use rather than
fixing a number: sweep at increasing margins, find where the finding count jumps because the
library's own default field offsets have started reporting, and set the margin just below that.

**Origin.** *"Text overlap around C1101"*, *"J601 has text overlapping component body. Check all
the schematic for instance of this and fix if required."*, and round 3: *"This all needs fixing
before we can proceed."*

**Status.** **REFINES** *"Nothing overlaps, ever: no text over components, wires, or other text."*
The rule exists; what is missing is that it must be *measured*, that "no overlap" is a weaker bar
than "clearance", and that a field must be compared against its **own** symbol's outline — the
commonest single miss.

**Disposition.** **APPROVED** — as written. Fold into the named rule as added detail; do not add a new bullet. The clearance margin is left as a calibration method rather than a number: a fixed figure is only right for the library it was measured against, and a library that places its fields tighter would see normal house placement reported everywhere. The method — sweep upwards, find where the count jumps, sit just below it — transfers; the number does not.

### 13. Character advance and text box geometry

**Rule.** Do not trust a remembered figure for character width — measure it on a render before
relying on it. Whatever the figure, scale it by the field's own font size: block titles are
typically bold and half again the default size, so a box computed at the default size comes back a
third too narrow. A field or label justified `bottom` puts its glyphs **above** the
anchor and one justified `top` puts them below; centring everything vertically hides
reference-over-value collisions completely. Text grows leftward when `justify right` **XOR** symbol
at 180° **XOR** mirrored — but a *label* takes no 180° flip, so its growth is justify-driven alone.

**Origin.** Measured off renders during rounds 1–4, each figure confirmed against at least one
render before being trusted.

**Status.** **CONTRADICTS** *"budget the rendered length of every net label (~1.06 mm per character
at 1.27 size)"*.
Current skill: `~1.06 mm per character`.
Proposed: `~1.19 mm per character at size 1.27, scaled by the field's own font size`.
On a 15-character label that is 1.95 mm of difference — enough to pass a real collision.

**Disposition.** **APPROVED in the safer form.** The rule now says to measure the character advance on a render rather than quoting a figure, so the skill carries no second number to go stale. The font-size scaling and the justify/growth geometry are exact and stay as written. Fold into the named rule as added detail; do not add a new bullet.

### 14. A graphical line must never be confusable with a wire

**Rule.** Keep block-box borders, notes' leader lines and any other graphic clear of the paths
wires take. A graphic running along or through a wire's route, or a wire jogging along a border,
must be moved: the reader cannot tell them apart at review zoom.

**Origin.** *"wire obscured by a graphical line"*.

**Status.** **NEW.** The skill governs bounding boxes' appearance ("outline only — never colour or
fill") but not their collision with wiring.

**Disposition.** **APPROVED** — as written.

### 15. Block boxes cross nothing

**Rule.** A block bounding box must not cross a component body, a sheet boundary, or another block
box. Its top edge must be inside the drawing area — on a KiCad frame the drawing area starts inside the
outer border, below the ruler band, not at the border itself.

**Origin.** *"`temp_sense` content crosses the top sheet boundary"*, *"The `+5VA` bridge-excitation
label/wiring falls outside the sheet boundary at the top"*, and the verification round, where a
hand-dragged border stopped in the middle of the IC the block is named after.

**Status.** **REFINES** *"Size the box to the block's real extent, then re-check the title still
fits inside it."* Sizing is covered; crossing a body or the frame is not.

**Disposition.** **APPROVED — checkable half only.** The rule keeps *a box crosses nothing*; the sentence about growing a box past the part it names is removed, because inferring a box's intent is a judgement, not a check. Fold into the named rule as added detail; do not add a new bullet.

---

## C. Symbols, designators and libraries

### 16. Rotate the part on the schematic; keep its text horizontal

**Rule.** Rotating a part on the schematic is acceptable and normal. Needing an orientation is not
a reason to make a library variant — use the standard symbol and turn it. Keep the reference and
value rendering **horizontal**: a property's `(at x y angle)` angle is *relative to the symbol*, so
compensate the field angles — 270 on a symbol at 90, 90 on one at 270 — or the text comes out
sideways. Verify it in a render.

**Origin.** *"`R1128`-`R1133` use a different 100R symbol — why, and unify"*, ruled *"unify onto the
standard 100R symbol regardless"*, then settled directly: *"It is perfectly acceptable to rotate a
part in a schematic. Needing to rotate a part should not require a new library variant to be
made."*

**Status.** **CONTRADICTS** *"Orientation variants are pre-rotated in the library, never
instance-rotated — this keeps reference/value text horizontal. If a part must sit horizontally
(in-line series resistor, rotated FET), make a `_H`/pre-rotated local variant."*
Current skill: pre-rotated library variant; never rotate the instance.
Proposed: rotate the instance; no variant is needed for orientation. The *purpose* of the old rule
— reference and value text rendering horizontal — is kept, and the Rule above says how to achieve
it while rotating.

**Disposition.** **APPROVED — this one REPLACES the text it contradicts.** It is the single
exception to folding a change in as added detail: the existing sentence says the opposite, so it
comes out and the Rule above goes in its place. The `_H`/pre-rotated-variant sentence goes with it.

### 17. Reference-designator prefixes follow the part's function

**Rule.** The prefix says what the part is, not where it sits in the circuit. A coaxial or board
connector is `J` even if it sits in a filter chain; `FL` is a filter. When in doubt, take the
library symbol's own default prefix — overriding it on the instance is how these diverge.

**Origin.** *"`FL501`/`FL502` are connectors — re-designate as `J`"*.

**Status.** **NEW.**

**Disposition.** **APPROVED** — as written.

### 18. Designators are unique across the whole project, and per-sheet ranges keep them so

**Rule.** Fix a designator scheme for the project and hold to it — sequential through the
schematic, or per-sheet ranges from the page number — and apply it to power symbols and power
flags as well as parts. Whichever scheme is used, designators must be unique across the whole
project: two sheets both starting at `U1` do **not** raise an ERC error, they silently merge into
one component at netlist time.

**Origin.** Established during integration on this project; the failure mode was then demonstrated
for real in the verification round (item 26).

**Status.** **NEW.**

**Disposition.** **APPROVED as designer discretion.** Either scheme is fine — sequential through the schematic, or page number × 100 — and which one suits depends on the project's setup defaults. The rule now says *fix a scheme and hold to it*. What is not discretionary is uniqueness across the project, and that the ERC will not catch a clash.

---

## D. Test and debug provision

### 19. Test coverage lives on the page it covers

**Rule.** Test points, probe headers, scope hooks and debug connectors belong to the block whose
nets they observe. Do not create a test-and-debug sheet. If you find a sheet that already contains
test coverage, do not collapse it without asking the designer first.

**Origin.** *"Can all of the test_debug page be implemented on the relevant circuits page?"*

**Status.** **NEW.** The skill has a related but different rule about *what form* debug access
takes; it says nothing about *which sheet* it lives on.

**Disposition.** **APPROVED**, with the addition now carried in the rule: if a sheet already contains test coverage, do not collapse it without asking the designer first. The reservation I raised about large designs is withdrawn — the rule globalises as written.

### 20. One keyed header beats a row of digital test points

**Rule.** For a digital interface, fit the house keyed logic-analyser header rather than individual
test points per signal — one plug, one ground reference, no clip slipping off a series terminator.
Tap the bus on the controller side of any series terminator or isolation link so the header still
sees the bus with a link lifted. Keep the ground hooks the probe leads clip to.

**Origin.** *"Rather than using individual test points for the digital interface, can you use the
amodokicadlib header for the logic analyser?"*

**Status.** **REFINES** *"Bring-up/debug access goes on simple populate-if-needed connectors (DNP
by default), not bare test points."* Same direction; this names the specific case, the house part
and the "tap which side of the terminator" detail.

**Disposition.** **APPROVED** — as written. Fold into the named rule as added detail; do not add a new bullet.

### 21. Dual scope points at regulator outputs

**Rule.** Every regulator output gets a **dual** test point — signal pad and ground pad adjacent —
so a scope probe and its ground clip land together.

**Origin.** *"At the output of all regulators, use a dual test point, so that I can hook up an
oscilloscope probe."*

**Status.** **NEW.**

**Disposition.** **APPROVED** — as written.

### 22. No test coverage on feedback nodes or high-speed signals

**Rule.** Never place a test point on a PSU feedback node — the stub is in the control loop. Do not
place test coverage on very high-speed interfaces; probe the same information somewhere it costs
nothing, such as a receiver's single-ended output rather than the terminated differential pair.

**Origin.** *"Also, do not place test coverage on PSU feedback nodes."* and, earlier, *"not
advisable to place test coverage on very high speed interfaces or signals"*.

**Status.** **NEW.**

**Disposition.** **APPROVED** — as written.

### 23. Test-point silkscreen names

**Rule.** Every test point carries a short name saying what it measures, taken from the net it
actually lands on, **under 6 characters**. In the rare case where shortening a net's name that far
would hide its meaning, a longer name is acceptable.

**Origin.** *"Across the schematic, can you label all of the TPs with some text for what they
measure … keep them as short as possible (< 6 characters)"*.

**Status.** **NEW.**

**Disposition.** **APPROVED**, with the exception now carried in the rule: where shortening a net's name below six characters would hide its meaning, a longer name is acceptable.

---

## E. Verification

### 24. `kicad-cli` exit codes and the silent-pass traps

**Rule.** Three traps, all of which produce a clean-looking result from a broken schematic:

* `kicad-cli sch erc` **exits 0 even when it finds violations** unless
  `--exit-code-violations` is given. Always pass it, and always read the report.
* `kicad-cli sch erc` prints **"Found 0 violations" when the sheet failed to load** — the
  "Failed to load schematic" line goes to **stderr**. Never accept a clean ERC without also
  checking stderr and the component count from a netlist export.
* **An invalid token truncates a sheet silently.** KiCad stops parsing at the bad token, keeps
  everything before it and drops the rest, with no error, and the plotter still renders what
  survived. The tell is a component count well below what the sheet contains.

**Origin.** All three hit during this review; the third cost a sheet truncated to 349 of 409
components behind a "clean" render.

**Status.** **NEW** as a group. The skill's verification list assumes ERC output is trustworthy.

**Disposition.** **APPROVED** — as written.

### 25. Node-set invariance is the proof for geometry work

**Rule.** For any pure-geometry rework, compare the **multiset** of per-net node sets — each net as
a set of `(refdes, pin)` — before and after. Net *names* may legitimately change; membership may
not. "ERC is still clean" is not a substitute: ERC passes happily on a wire that merged two nets.

**Origin.** Used throughout; it caught a real short (two gate nets merged by collinear stubs) and a
real disconnection (two resistors moved without their ground flag) that ERC alone did not localise.

**Status.** **REFINES** *"Pure-geometry reworks proven safe by comparing per-net node sets of
before/after netlists (names may change; membership may not)."* Already present and correct; the
addition is **multiset** — comparing name-keyed dictionaries reports every renamed net as a
difference and buries the real one.

**Disposition.** **APPROVED** — as written. Fold into the named rule as added detail; do not add a new bullet.

### 26. Annotation is not checked by ERC — check it at the netlist

**Rule.** An unannotated part (`J?`, `R?`) passes ERC with **zero violations**. Two of them merge
into a **single netlist component** carrying duplicated pin numbers and only one part's value and
footprint — so a real part silently vanishes from the BOM and its nets land on the wrong footprint.
The check is the netlist export, which prints **"schematic has annotation errors"**, plus a
component-count comparison. To repair, set the specific references back rather than running a blind
re-annotate, which renumbers unrelated parts.

**Origin.** The verification round: two connectors on different sheets lost their designators during
manual editing and merged into one 17-node component.

**Status.** **NEW**, and the sharpest of these: it is a defect class that every automated check in
the current skill's list passes.

**Disposition.** **APPROVED** — as written.

### 27. A reference designator lives in two places

**Rule.** A symbol's designator is stored both in its `Reference` property and in its
`(instances … (reference …))` entry. A sheet where the two disagree loads without complaint and
exports the **instance** value. Change both together.

**Origin.** Found while repairing item 26.

**Status.** **NEW.**

**Disposition.** **APPROVED** — as written.

### 28. Renaming a net is a sweep, not an edit

**Rule.** When a net's name changes, sweep every place the old name appears: the label, any power
symbol, test-point silkscreen names, title-block comments, sheet notes, block notes and the
project documentation. A net whose name disagrees with what the drawing says about it is worse than
either name alone.

**Origin.** *"You did not update the other documentation on the power_rails sheet for the 6V change!
Test point and net label are all still wrong."*

**Status.** **NEW.**

**Disposition.** **APPROVED** — as written.

### 29. The render is the last word, and a checker miss is a checker bug

**Rule.** After every automated sweep, render the changed areas and look. When a render disagrees
with a checker, the checker is wrong: fix the checker, then re-sweep the whole design with it — the
same blind spot is almost never in one place only.

**Origin.** The skill already says this; this round proved it five times, each time finding a whole
class rather than an instance.

**Status.** **REFINES** *"treat a checker miss that a render reveals as a checker bug to fix."*
The addition is the second half: **re-sweep design-wide after fixing the checker.** Each of the five
blind spots found this round turned single-figure finding counts into double-figure ones.

**Disposition.** **APPROVED** — as written. Fold into the named rule as added detail; do not add a new bullet.

---

## F. Tooling practice

### 30. Never infer free space from a partial dump

**Rule.** Before placing anything, list **everything** the sheet draws inside the target rectangle —
wires, bodies, fields, labels, notes, borders. A partial wire dump is how new parts land collinear
with existing nets.

**Origin.** Round 1: capacitor stubs placed into a band believed empty landed collinear with two
gate verticals and shorted them; ERC reported the short two sheets away.

**Status.** **NEW.**

**Disposition.** **APPROVED** — as written.

### 31. A re-runnable edit script pins its base commit

**Rule.** A script that rebuilds sheets from git must name an explicit **base commit**, not `HEAD`.
Rebuilding from `HEAD` works exactly once: after the script's own commit lands, `HEAD` already
contains its edits and a re-run double-applies them. After any manual editing, such a script must
not be re-run until its base is re-pinned — it would overwrite the manual work.

**Origin.** Hit during round 3; stated as a hand-over warning before the captain took the helm.

**Status.** **NEW.**

**Disposition.** **APPROVED** — as written.

### 32. Edit primitives assert that they changed something

**Rule.** Every programmatic edit asserts it matched. `str.replace` says nothing when it matches
nothing, so a "successful" run can have done none of its edits.

**Origin.** Round 3, where five of six edits silently did nothing behind a success message.

**Status.** **NEW.**

**Disposition.** **APPROVED** — as written.

### 33. Multi-unit parts are keyed by symbol uuid, not by refdes

**Rule.** A multi-unit part has one `Reference` field per unit under one refdes. Anything that walks
fields must key them by the symbol's **uuid**; keying by refdes collapses every unit onto one point.

**Origin.** Round 3, which stacked all five units' references of a quad receiver on a single point.

**Status.** **NEW.**

**Disposition.** **APPROVED** — as written.

---

## G. Review surface

### 34. The design is reviewed in the KiCad files, never in an export

**Rule.** Never produce, commit or hand over a review PDF. An engineer reviews the KiCad files
themselves. An export is a snapshot: it goes stale the moment anyone saves, it cannot be probed,
cross-probed or netlist-checked, and reviewing it invites comments against a drawing that no longer
matches the design. Renders are your own self-check — export them to a scratchpad, look at them,
and leave them there; they are not a deliverable and they do not enter the repository.

**Origin.** *"The engineer should always review the KiCad files, and not a pdf. Do not generate
one."*

**Status.** **REFINES** *"Never produce or commit review PDFs — the client reviews in the KiCad
GUI."* The stance is already the skill's; what is added is the reason, which is what makes it
stick, and the explicit permission for scratchpad renders so the rule is not read as forbidding
looking at your own work.

**Disposition.** **APPROVED** — as written, and the stance stays **absolute**: no per-project
deviation. Fold into the named rule as added detail; do not add a new bullet.

---

## Rulings on the flagged items

I flagged seven items as ones I would not globalise without a decision. All seven are now ruled on;
the rulings are carried in the items themselves, and repeated here so the reasoning is in one
place.

| # | Item | Ruling |
|---|---|---|
| 1 | 16 — instance rotation vs pre-rotated variants | **Ruled: rotate the part.** *"It is perfectly acceptable to rotate a part in a schematic. Needing to rotate a part should not require a new library variant to be made."* The item now **replaces** the never-instance-rotate text rather than folding into it, keeping that rule's purpose — horizontal reference and value — as the condition on rotating. |
| 2 | 13 — character advance | **Use the safer version.** The rule now says to measure it on a render rather than quoting a number. |
| 3 | 12 — the clearance margin | **Left to my judgement; decided: no fixed number.** The rule gives a calibration method instead — sweep at increasing margins, find where the finding count jumps because the library's own field offsets have started reporting, sit just below that. A number measured against one library is wrong for the next one; the method is not. |
| 4 | 19 — test coverage on its own sheet | **Disagreed with my reservation: test coverage goes on the sheet.** The rule globalises as written and my large-design caveat is withdrawn. The one addition is that an existing sheet carrying test coverage is not collapsed without asking the designer first. |
| 5 | 15 — block boxes | **As proposed: the checkable half only.** "A box crosses nothing" stays; inferring what a box was meant to enclose does not. |
| 6 | Review PDFs | **Ruled: no PDF, ever.** The skill's never-commit stance stays absolute, and gains the principle above as item 34. In this repository the committed PDF has been deleted and the decision that authorised it is superseded. |
| 7 | 4 — row-detection thresholds | **Approved as proposed.** The numbers live in the tool; the skill states the rule. |

---

## Summary for the skill update

* **34 items, all approved.** Nothing is held.
* **Refinements are folded into the named existing rule as added detail** — they do not become new
  bullets. Items 1, 2, 3, 4, 8, 9, 10, 11, 12, 15, 20, 25, 29 and 34 name the rule they extend, and
  item 13 amends a figure inside an existing line in the same way.
* **One item replaces rather than extends: item 16.** The existing "never instance-rotated"
  sentence, and the `_H`/pre-rotated-variant sentence with it, come out; the Rule in item 16 goes
  in their place. That rule's purpose — reference and value rendering horizontal — is preserved as
  the condition on rotating.
* **Origins are not pushed.** They exist in this document only.
* **The Rule text is the only text that transfers**, and it is already written in plain
  designer-to-designer style: no process narration, no roles, no review rounds, no project names.

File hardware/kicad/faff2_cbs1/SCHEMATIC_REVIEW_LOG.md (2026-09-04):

# FAFF 2 CBs_1 - Schematic Review Log

Required by the `schematic-style` skill: the client's verbatim review advice lands here first,
with its resolution. Newly general rules migrate from here into the skill itself.

**Consult this log before starting schematic work.** One table per review round.

## Round 0 - skeleton (2026-09-02)

No client review yet: the schematic is a skeleton with no circuitry. This round records the
in-house instructions that already bind the schematic work, so they are not lost between rounds.

| # | Source | Point (verbatim where quoted) | Resolution |
|---|---|---|---|
| 0.1 | Captain, via firstmate | "use the Amodo KiCad library for all components… prefer existing Amodo parts; create new parts ONLY where absolutely necessary, and new parts are created in that local library (not scattered in the repo)" | Project `sym-lib-table` / `fp-lib-table` bound via `${AMODO_KICAD_LIB}`. DEC-0015; rule in `AGENTS.md` |
| 0.2 | Captain, via firstmate | New-part additions to a category file must be reported in a status line so concurrent edits can be serialised | In `AGENTS.md` under parallel block work |
| 0.3 | Captain, via firstmate | KiCad 9 only | DEC-0017 |
| 0.4 | EEE Hardware Design Standard draft | "not advisable to place test coverage on very high speed interfaces or signals" | No test points on ULPI or QSPI. DEC-0018 ruling 1; `TEST_PLAN.md §2.2` |
| 0.5 | EEE Hardware Design Standard draft | Test point type chosen per net: `TestPoint` / `TestPointHook` / `TestPointDual`; GND hooks beside signal hooks | `TEST_PLAN.md §2.1`; DEC-0018 ruling 2 |
| 0.6 | EEE Hardware Design Standard draft | Use a coaxial connector for nets you will scope or inject into repeatedly (U.FL, U.FL-to-BNC adapter in the EEE lab) | `TEST_PLAN.md §2.3`; DEC-0018 ruling 4 |
| 0.7 | `schematic-style` skill | Top sheet should be the block diagram wired with sheet pins | **Deliberate temporary deviation** — root is unwired until child sheets declare hierarchical labels. DEC-0009 |
| 0.8 | Self-check (render sweep) | Full-length sheet titles overran the A3 title-block field and clipped at the page border on `mcu` | Titles shortened to `CBs_1 - <block>`. DEC-0020 |

## Round 1 - the complete schematic, ready for review (2026-09-03)

All ten blocks are drawn, the root sheet is wired and the design is internally consistent.
**No client review has been held yet** - this round records the in-house state the pack is
submitted in, and the points the captain is asked to rule on.

### Design totals

| | |
|---|---|
| Sheets | 11 (root + 10 blocks), A3, KiCad 9 `20250114` |
| Components | 409 - `power_entry_24v` 28, `power_rails` 60, `test_debug` 10, `loadcell_afe` 59, `linear_encoder` 26, `temp_sense` 44, `nvm_calibration` 15, `ui_io` 40, `mcu` 50, `motor_drive` 77 |
| Nets | 253 |
| Sheet pins on the root | 113 over 55 net names; 70 wires, 3 junctions, 0 crossings |
| Isolation links / current breaks | 32 0R links (`TEST_PLAN §3.3`) |
| Test points | across all ten blocks per `TEST_PLAN §4` |
| Libraries | Amodo house lib via `${AMODO_KICAD_LIB}`; project-local `faff2_afe`, `faff2_motor`, `faff2_periph`, `faff2.pretty` via `${KIPRJMOD}` |

### Verification state

| Check | Result |
|---|---|
| `kicad-cli sch erc --severity-all`, nothing suppressed | **0 errors, 0 warnings** (DEC-0021) |
| Designators | 0 unannotated, 0 out of range, 0 duplicates; power symbols too (DEC-0024) |
| Footprints | all 409 components assigned; all 51 distinct footprints resolve to a library file |
| `schematic-style` overlap checker | root sheet clean; 11 findings elsewhere, every one a confirmed checker artefact (`docs/decisions/actuator-sch-integrate.md §7`) |
| Render sweep | all 11 pages at 10 px/mm |
| Review surface | the KiCad files themselves - no PDF is generated (`DEC-0028`) |

### Open points for the captain

| # | Point | Recommendation |
|---|---|---|
| 1.1 | **OQ-07 - `RAIL_PGOOD` has no MCU pin.** It drives `D303` and `TP308` inside `power_rails` and nothing else, so firmware cannot read power-good. | Allocate one of the spare MCU pins in the `.ioc` (`SPARE_PA8/PA10/PB4/PB7/PC13/PE3/PE7`). One label in each of two sheets plus a root sheet pin. DEC-0023 |
| 1.2 | **`AM26LV32CDR` (U601) is obsolete.** TI's addendum of 14-Oct-2025 in `datasheets/AM26LV32.pdf` lists the C-grade SOIC parts as Obsolete. | Move to **`AM26LV32IDR`** - same D package, -40 to 85 °C, Active. Needs a JLC stock check, so it is raised rather than made. Footprint unaffected |
| 1.3 | **88 components carry no datasheet URL.** All are Amodo house-library passives and test points whose `Datasheet` field is blank or `~` **in the read-only house library**. `schematic-style` requires a working web URL on every library part. | Upstream house-library fix. Overriding the instances locally would diverge from the house lib for no gain |
| 1.4 | **DRV8323S land pattern is `FPLifecycle draft`.** Sourced from TI 4219112/A via the RHA0040B equivalence because `SLVSDJ3D` omits the RTA drawing. | Confirm the reasoning in DEC-0025 and check the land against a real part before the first order |
| 1.5 | **A review PDF is committed** under `docs/review/`, which `schematic-style` forbids. | The integration brief asked for it explicitly; recorded as a deliberate deviation in DEC-0026. Confirm the client still reviews in the GUI |

### In-house points closed during integration

| # | Point | Resolution |
|---|---|---|
| 1.6 | Round 0 point 0.7 - "top sheet should be the block diagram wired with sheet pins", deferred as a temporary deviation | **Closed.** The root is wired: 113 sheet pins, aligned rows so 48 of the 55 nets are single straight wires. DEC-0022, closing DEC-0009 |
| 1.7 | `CONFIG_SPI_MISO` declared `output` by `motor_drive` and `tri_state` by `temp_sense`; `actuator-sch-afe.md §3` flagged it for integration | **Closed.** Both `tri_state` - three devices share the wire, each driving only while its own chip select is low |
| 1.8 | `loadcell_afe` and `temp_sense` both annotated power symbols from `#PWR001`, silently merging 19 references | **Closed.** Renumbered to the per-sheet ranges; rule written into `AGENTS.md`. DEC-0024 |
| 1.9 | `RAIL_PGOOD` exported as a hierarchical label with no consumer anywhere | **Closed** as a sheet-local label; see 1.1 for the open half. DEC-0023 |
| 1.10 | `TEST_PLAN §3.3` asked for a rail link from `power_rails` to each consumer block; the block wave drew one break per *rail* instead | **Closed.** `TEST_PLAN §3.2/§3.3` rewritten against what is drawn, with the 32 links tabulated and the bring-up steps naming the link each one opens |
| 1.11 | Four sheet notes still told the reader the root was unwired and to expect `hier_label_mismatch` | **Closed.** `motor_drive`, `mcu`, `power_entry_24v`, `test_debug` corrected |

---

## Round 1 review - the captain's pass over the drawn schematic (2026-09-03)

The captain reviewed the completed schematic sheet by sheet. His points arrived in
batches and were applied in three parallel streams; the numbering below is by
batch, not by arrival. Reasoning for every judgement call is in
[`docs/decisions/actuator-sch-review-r1.md`](../../../docs/decisions/actuator-sch-review-r1.md)
(power sheets, `motor_drive`, and the design-wide sweep),
[`actuator-rev-afe.md`](../../../docs/decisions/actuator-rev-afe.md) and
[`actuator-rev-testdebug.md`](../../../docs/decisions/actuator-rev-testdebug.md).

### Placement and drawing style

| # | Point (captain's words) | Sheet | Resolution |
|---|---|---|---|
| R1.1 | "Mirror the input power connector so that the pins come out left to right, and wires don't have to route around its body." | `power_entry_24v` | **Done.** `J201` mirrored and moved so all five pins leave rightward; no wire passes the body |
| R1.2 | "Have the input protection FET horizontal, so that pins 1 and 5 are horizontal not vertical." | `power_entry_24v` | **Done.** `Q201` at 90° - drain left, source right, gate down; the gate net no longer loops round the body |
| R1.3 | "Where you have a potential divider ... make sure they are vertically aligned." | `power_entry_24v` | **Done.** `R201`/`R202` share one column; the gate node is a 3-way tee, not a 4-way |
| R1.4 | "D201 is in parallel with C204, etc, so graphically it should also be placed vertically like C204 etc. Same for D202." | `power_entry_24v` | **Done.** Both diodes vertical; `D201`'s GND flag joins the shunt bank's line |
| R1.5 | "It would be nice if GND connections for parallel components are vertically aligned." | `power_entry_24v` | **Done.** `R206` and `C207` GND flags both at y=96.52 |
| R1.6 | "Never ever use a 4-way net connection ... Also, do not place test coverage on PSU feedback nodes." | `power_rails` | **Done.** `TP301` and `TP305` deleted - one edit satisfies both halves, because removing the test point is what leaves each feedback node a 3-way tee |
| R1.7 | "At the output of all regulators, use a dual test point, so that I can hook up an oscilloscope probe." | `power_rails` | **Done.** `TestPointDual` on all five rail outputs, hung below the rail on a stub so the pads do not straddle the wire they tap |
| R1.8 | "Series output zero ohm links for regulators should be placed horizontally, not vertically." | `power_rails` | **Done.** `R305`, `R306`, `R307`, `R312` |
| R1.9 | "Ferrite beads used for rail filtering should be placed horizontally ... to keep flow of power in one direction, without un-necessary corners." | `power_rails` | **Done.** `FB301` in line on the `+3V3` rail |
| R1.10 | "Power LEDs should also ideally be placed vertically." | `power_rails` | **Done.** `D303`, anode up out of `R314` |
| R1.11 | "R1101 and R1102 are in series, so I think the comment is wrong about fitting one vs the other. Also, the comment says R101 and R102, which I think is a mistake?" | `motor_drive` | **The refdes were wrong** - now `R1101`/`R1102`. The parts are genuinely two 0R in series, both fitted (D-MOT-14); the note is rewritten to say so and to give each link its own job |
| R1.12 | "Text overlap around C1101" | `motor_drive` | **Done.** The bulk column was on an 8.89 pitch that put `C1101`'s reference on `C1102`'s body; respaced, and `TP1103` moved out of the capacitor value row |
| R1.13 | "Same as other sheet review for sheet entry / exit labels justification. This text should not overlap the wires." | `motor_drive` | **Done.** Eight labels: seven took their wire from the left while facing left, so the wire ran through the text; `+24V_SW` ran vertically into the block title. All now face the way their wire arrives |
| R1.14 | "J601 has text overlapping component body. Check all the schematic for instance of this and fix if required." | design-wide | **Done.** `J601` by the encoder worker; the design-wide sweep found and cleared 16 more, several of which the bundled checker cannot see (see below) |
| R1.15 | "GND connections are upside down. You must never ever do this." | `temp_sense`, design-wide | **Done.** `C701`/`C702` by the temp worker; the sweep confirms **0** of the 285 power symbols is rotated or mirrored |
| R1.16 | Graphic/drawing lines shadowing electrical wires | design-wide | **Done.** One real case: `power_rails` block D's bottom border ran along the last `PWR_FLAG`'s wire. The flag column moved up 2.54; the sweep finds no other |

### Design questions answered

| # | Point | Answer |
|---|---|---|
| R1.17 | "For regulators in general, can you tend towards using the same parts as used in this design: ARIA_EITSYS_CBs_1" | `U301` swapped to that design's **LMR51610XFDBVR** with divider, inductor and PGOOD re-derived from TI SLUSEY1B. `U304` keeps the LMR33630 (its rail's 1.1 A budget exceeds the LMR51610's 1 A) and both 5 V LDOs keep the TPS7A20 (7 µV<sub>RMS</sub> against the ADPL42005's 32, on the rail carrying `REQ-FF-04`). Both exceptions stand pending the captain |
| R1.18 | "Should there be some bulk decoupling on this sheet? Also, decoupling per FET, or is this not usually done?" | Bulk was already there (210 µF at the bus entry, plus the driver's own VM bypass); **what was missing was capacitance at the bridge**, which TI asks for in as many words (SLVSDJ3D §10/§11.1). Added one 2.2 µF + 100 nF pair per half-bridge. **Not per FET** - a capacitor across one MOSFET is a snubber, not decoupling, and is a bring-up decision |
| R1.19 | "Can all of the test_debug page be implemented on the relevant circuits page?" | **Done** by a parallel worker: `test_debug.kicad_sch` no longer exists, and the standing rule is in `AGENTS.md` |
| R1.20 | "Is the intention that U501 provides / outputs the reference signal?" | Answered on the sheet by the AFE worker: **no** - the ADS1235 has no reference output; `REFP0`/`REFN0` are inputs, and what it measures against is the load cell's own excitation |
| R1.21 | "Rather than using individual test points for the digital interface, can you use the amodokicadlib header for the logic analyser?" | **Done** by the AFE worker |

### Design-wide sweep

| # | Point | Resolution |
|---|---|---|
| R1.22 | "Power labels are missing on most of the power flags on the design" | **Done.** 92 hidden rail names on `loadcell_afe`, `motor_drive` and `temp_sense` are now visible, placed to the house pattern (GND below the symbol, rail arrows above) and collision-checked. All 285 power symbols now read |
| R1.23 | "Across the schematic, can you label all of the TPs with some text for what they measure ... keep them as short as possible (< 6 characters)" | **Done.** All 83 test points named from the net each actually lands on; longest is 5 characters. Table in `actuator-sch-review-r1.md` |

## Round 3

| # | Point | Resolution |
|---|---|---|
| R3.1 | "A deeper text-overlap pass — extend detection to text against wire segments and symbol outlines including rotated and mirrored ones, sweep every sheet, fix every hit, and record the improved checker. This all needs fixing before we can proceed" | **Done.** `tools/check_text_clearance.py`, calibrated at 0.35 mm; both screenshotted cases reproduced and fixed; 60 findings to 13, then a fifth blind spot found by render (labels and bodies were obstacles, never subjects) took the sweep design-wide. Reasoning in `actuator-sch-review-r1.md` |
| R3.2 | "Replace `TP707`–`TP711` with the Amodo keyed logic-analyser header" | **Done.** `J703`, an `8510-4500PL` as on `J502`/`J603`; channel map copies `J603` pin for pin. This is `actuator-rev-afe.md` §7's own recommendation applied |
| R3.3 | "Swap both 5 V LDOs to `ADPL42005ACPZ-5.0-R7`, fixed output, and re-derive the passives from the datasheet" | **Done.** DEC-P3 superseded. Every value from `datasheets/ADPL42005.pdf` (a mirror copy — analog.com is unreachable from the build environment). `CIN` 1 µF → 10 µF is the only passive the datasheet forced. **Two items for the captain:** wiring the new `PG` pins into `RAIL_PGOOD`, and whether to raise `+5V5` now that the 6.0 V ceiling is gone |
| R3.4 | "Respace the grazing power-label placements and find the TIM1 note a clean home" | **Done.** The improved checker turned 13 into 60; 57 cleared, ERC 0/0 and node sets identical. The TIM1 note sits beside U1101's logic inputs — round 2's "nothing fits in this block" was wrong, 495 positions do. Three left, both argued out in `actuator-sch-review-r1.md`: `#PWR1131` needs 4.45 mm in a 2.54 mm bus field (**for the captain**), and `#PWR327` is a 0.13 mm graze with every direction taken |
| R3.5 | "Leave ESD off the AFE inputs" | **Done** — recorded as a closed decision |

## Round 4

| # | Point | Resolution |
|---|---|---|
| R4.0 | "Parallel components share ONE GND-flag height — sweep ALL sets of parallel capacitors and parallel parts across the design" (good: the `C1113` row; bad: `C1101`/`C1102` staggered) | **Done, and recorded as standing style** in `AGENTS.md`. `tools/gnd_rows.py` finds every breach rather than relying on the eye; four rows were out, all six flags now level |
| R4.1 | "Apply that alignment around `C315`/`C316`/`R308` — it also fixes the R308 overcrowding" | **Done.** Levelling put each flag's name 0.26 mm inside the EN divider's top resistor, so the divider column moved 2.54 mm left; both clear by 2.28 |
| R4.2 | "`PGND` pin on `U304` overlaps `C318`" | **Done.** `U301` is the same regulator wired the same way and its PGND ground hangs 1.27 mm below the pin; `U304`'s hung 6.35 mm down, into C318's lane. Matching `U301` also closed both of round 3's residual findings |
| R4.3 | "The `+5VA` bridge-excitation label/wiring falls outside the sheet boundary at the top" | **Done.** The drawing area starts at y=11.94 (measured off a render); the whole excitation cluster dropped 6.35 mm |
| R4.4 | "The rail probe header belongs on THIS sheet" | **Done.** `J1004` → **`J301`** on `power_rails`, block D. Its own note had already named this sheet as the alternative home |
| R4.5 | "`FL501`/`FL502` are connectors — re-designate as `J`" | **Done → `J503`/`J504`.** No reason survives: they are `Amodo_Connectors:CONUFL001-SMD`, U.FL coaxial connectors with connector footprints, and the library symbol's own default prefix is `J`. `FL` designates a *filter*; they sit in a filter chain, which is the only reading that explains it. `DEC-A14` |
| R4.6 | "Add a very concise text note directly next to `J501`" | **Done.** Five lines under the connector; the full table stays in the notes column |
| R4.7 | "`R601` and `R608` are the same package — keep ONE" | **Done, `R608` removed.** Reverses part of review point R6; the reasoning is better — to meter head current you replace `R601` with a shunt |
| R4.8 | "Remove `R609` entirely — `FB601` can be lifted" | **Done.** `D602` stays: a second clamp *position* for a different part is not the same argument |
| R4.9 | "`temp_sense` content crosses the top sheet boundary" | **Done.** Six rectangles across `temp_sense` and `mcu` started at y=11.43, half a millimetre above the drawing area. Nothing is above the boundary now |
| R4.10 | "Add 100R between the SWD header and the `+3V3` pin" | **Done, `R1015`** — the same series resistance `ARIA_EITSYS_CBs_1` puts on the same pin |
| R4.11 | "Swap the SWD header to the STM32 14-way version as in `ARIA_EITSYS_CBs_1`" | **Done.** `Amodo_Connectors:SAMTEC_SHF-107-01-L-D-SM`, pinout traced pin by pin from that repo's `J11`. **One deviation, an addition:** `SWO` on pin 10, which is NC there — this design has SWO (`REQ-AR-15`) and dropping it would lose a capability |
| R4.12 | "`VBUS_MON` sheet exit has wrong justification/overlap; align the nearby capacitor GNDs" | **Done.** It was the only hierarchical label on the sheet with `justify left bottom`; all fifteen siblings read back over the wire. The four capacitor grounds are level under R4.0 |
| R4.13 | "`R1128`-`R1133` use a different 100R symbol — why, and unify" | **Done.** The reason was real but does not outweigh the divergence: round 2 added `faff2_passives:RES_TF_100R_0603_H`, a pre-rotated variant, so they could lie horizontally without instance rotation. Nine other 100R use the house symbol. All six now do too, rotated 90 with field angles compensated; the local variant is deleted |

### Captain rulings folded in from round 3

| # | Ruling | Done |
|---|---|---|
| A1 | PG into `RAIL_PGOOD`: **yes** | `R317`/`R318`, 1 k each. A dead 5 V rail is now visible at `D303`/`TP308` |
| A2 | Raise `+5V5`: **yes, 6.0 V or slightly above** | 6.110 V nominal, worst-case floor 6.009 V. `DEC-P10` shows the stack |
| A3 | `#PWR1131`: drag `R1120` and its flag down, no bus reroute | Done, 7.62 mm |

### What the bundled overlap checker cannot see

The sweep found three structural blind spots in `check_overlaps.py`, all measured
against renders. It grows every text field rightward regardless of `justify right`,
mirroring or 180° rotation; it measures text at ~1.06 mm per character where the
real advance is ~1.19; and it reflects a rotated symbol's body about the origin.
`tools/sch_geom.py` models all three correctly. **Run
`tools/check_text_clearance.py --margin 0.35`** instead of either: round 3 found
a fourth and fifth blind spot that my own model shared — a field was never
compared against its own symbol's outline, and net labels and symbol bodies were
only ever obstacles, never subjects.

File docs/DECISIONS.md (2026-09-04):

# FAFF 2 CBs_1 - Decision Log

Every judgement call made on the CBs_1 electronics, with its date, reasoning and evidence.
Standing instruction from the captain: **decide routine points and document them here** rather
than escalating. Escalate only where the decision is genuinely above the implementing engineer.

Append new decisions at the end; never renumber. If a decision is reversed, mark the original
**SUPERSEDED BY DEC-xxxx** and leave it in place.

Open questions live in `REQUIREMENTS.md` under [Open Questions](REQUIREMENTS.md#open-questions)
and graduate to a `DEC-` entry when answered.

---

### DEC-0001 - FAFF 1 power architecture is superseded, not inherited
**Date** 2026-09-02 · **Status** Accepted · **Scope** `power_entry_24v`, `power_rails`

FAFF 2 takes a single dedicated 24 V input on a KPJX-4S latching circular connector. The FAFF 1
barrel-jack alternate input, the power-OR stage and the USB-PD controller (CYPD3177-class) are
**all dropped**.

*Reasoning.* `SPEC §6` names 24 V and KPJX-4S outright, and separately states that the USB-C
port "will not power the hardware". With one supply there is nothing to OR. The FAFF 1 block
diagram is explicitly reference-only where it conflicts.

*Consequence.* No CYPD-class part is needed; `datasheets/README.md` records this so nobody
collects one.

### DEC-0002 - USB-C carries data only: no USB-PD, no bus power
**Date** 2026-09-02 · **Status** Accepted · **Scope** `mcu`

The USB-C receptacle implements USB 2.0 high-speed data via the USB3320 ULPI PHY and nothing
else. No PD negotiation, no sink capability, no bus-powered mode.

*Reasoning.* `REQ-EL-10`, verbatim from `SPEC §6`: "This port will not power the hardware."

*Consequence.* CC pins need only the passive resistors that make the port a valid
downstream-facing-device attachment; VBUS is not a supply on this board. The `mcu` task must
still decide how the device detects host presence — see OQ-01 and OQ-03.

### DEC-0003 - Linear encoder is the Bogen IKP11, not the Renishaw ATOM DX
**Date** 2026-09-02 (recording an earlier design-log decision) · **Status** Accepted ·
**Scope** `linear_encoder`

Part: `IKP11-Z1.4-P1-V5-D1-R0.5-F1000-C1`. 1 mm pole pitch, 5 V supply, RS-422 A/B/Z
differential outputs, 0.5 µm resolution, 1 MHz/channel max, 10-way 1.27 mm header.

*Reasoning.* Renishaw quoted a **34-week lead time** on the ATOM DX. Units and 300 mm magnetic
strip (`LMS-I1-L70-W5-A03-K`) were ordered from Bogen for immediate shipment. `ELOG`.

*Consequence.* The `SPEC` assumptions list and the specification design log still name the ATOM
DX — both are stale on this point. Incremental output means homing is required (`REQ-PS-10`),
which is why limit switches exist (`REQ-EL-09`). The electrical interface is an RS-422 receiver
into an STM32 timer in quadrature mode.

### DEC-0004 - The BLDC part number stays open
**Date** 2026-09-02 · **Status** Accepted · **Scope** `motor_drive`

The motor and its rotary encoder are deliberately **not** fixed by this design. Candidates in
`ELOG` include the Nanotec DB42M03 + NME2-UVW-W14-05-C, the StepperOnline 42BLS60-24-01, and
the SkysMotor 42BLS63-24-01 kit.

*Reasoning.* `ELOG` states it directly: "All of the above motor options are compatible with the
same version of the electronics (i.e. I can proceed with electronics design before finalising
specific motor and rotary encoder selection)."

*Consequence.* `motor_drive` must present a generic 3-phase output plus a rotary-encoder /
Hall connector that suits all three: incremental A/B, optional Z index, and three Hall outputs.
Working point for sizing: 0.0442 Nm screw torque, 1.229 A phase current, 240 rpm at 20 mm/s
with a 5 mm/rev lead (`CALC`).

### DEC-0005 - Temperature ADC is the ADS1120
**Date** 2026-09-02 · **Status** Accepted · **Scope** `temp_sense`

`ELOG` asked only for "an external ADC of some kind, probably over SPI". The `.ioc` net
`ADS1120_nCS` and the block diagram box "ADS1120 ADC (temperature measurement)" both name the
part, so it is settled.

*Reasoning.* Two independent authorities agree. The ADS1120 suits `REQ-EL-07` well: 16-bit
delta-sigma, integrated PGA, two matched IDACs for RTD/NTC excitation, internal reference, and
a 4-input mux that covers both probe channels from one device.

### DEC-0006 - QSPI force-profile RAM is fitted, not an option
**Date** 2026-09-02 · **Status** Accepted · **Scope** `mcu`

The external memory for force profiles is a fitted part on OCTOSPI1 port 1 in quad mode.

*Reasoning.* `ELOG` flagged a risk: "Ideally we will have space for some external RAM… This
might need to QSPI as I think ULPI pins collide with OctoSPI." On the STM32H723VET6 in LQFP100
**the collision does not occur**: ULPI occupies PA3/PA5/PB0/PB1/PB5/PB10-13/PC0/PC2_C/PC3_C
while OCTOSPI1 port 1 occupies PB2/PB6/PD11/PD12/PD13/PE2 — disjoint sets. The `.ioc` allocates
both simultaneously and the block diagram shows both. The risk that made it optional is gone.

*Consequence.* Treat it as a normal fitted subsystem. `REQ-AR-12`.

### DEC-0007 - Producer-owns-the-break: test points and isolation links belong to the block that generates the net
**Date** 2026-09-02 · **Status** Accepted · **Scope** all blocks

Test points, isolation links (0R / jumper / solder bridge) and current-measurement breaks are
**distributed into the block sheets**, not gathered onto one test sheet. The owning block is
whichever block *generates* the rail or signal. A separate `test_debug` sheet carries only what
is genuinely system-level: the SWD + USART3 debug header, the consolidated rail probe header,
and any link that sits between two blocks rather than inside one.

*Reasoning.* The brief allows either. Distributing gives every follow-up block worker a single
file to own with no shared-file contention, which is the whole point of the file-per-block
split (DEC-0008). "Producer owns the break" removes the only ambiguity — a link between
`power_rails` and `mcu` would otherwise have two plausible owners.

*Alternative rejected.* One central test-points sheet: it would become a merge-conflict
hotspot, since every one of the ten parallel tasks would need to edit it.

### DEC-0008 - Ten hierarchical blocks, one `.kicad_sch` file each
**Date** 2026-09-02 · **Status** Accepted · **Scope** repo structure

`power_entry_24v`, `power_rails`, `mcu`, `motor_drive`, `loadcell_afe`, `linear_encoder`,
`temp_sense`, `nvm_calibration`, `ui_io`, `test_debug` — each a hierarchical child of the root
sheet, each in its own file.

*Reasoning.* Follow-up tasks fill these blocks in parallel. KiCad rewrites a whole `.kicad_sch`
on every save, so two workers in one file means a guaranteed conflict. One file per block makes
parallel work conflict-free by construction. This also matches the `schematic-style` rule that
hierarchical sheets are standard once more than one block exists.

*Deviation from the brief.* The brief listed nine blocks plus an optional test/connectors
sheet; this is those nine plus `test_debug`, so ten. `test_debug` exists because DEC-0007
leaves a genuine system-level residue (debug header, rail probe header) that no functional
block owns.

### DEC-0009 - The root sheet is a block map, deliberately unwired
**Date** 2026-09-02 · **Status** Accepted, **closed 2026-09-03 by DEC-0022** · **Scope** `faff2_cbs1.kicad_sch`

The root sheet places all ten sheet symbols with a descriptive note, and draws **no** sheet
pins and **no** interconnect wiring.

*Reasoning.* A sheet pin only passes ERC once the child sheet declares a matching hierarchical
label, and those labels are created by the per-block tasks that own each child file. Drawing
sheet pins now would either break ERC or force this task to invent every block's internal
label set — which is exactly the component-level design the brief excludes, and would create
the cross-file coupling DEC-0008 exists to avoid.

*Note.* This decision was made before the block diagram arrived and **re-examined after**. The
diagram (`docs/FAFF-2-Electronics-Full.svg`) settles the interconnect topology, and the child
sheets are now reconciled against it, but it does not change the ERC mechanics above. Root
wiring is the first integration pass **after** the blocks are drawn.

*Deviation from `schematic-style`.* That skill says "top sheet = the block diagram wired with
sheet pins". That is the end state; it is not reachable from an empty skeleton. Recorded here
as a deliberate, temporary deviation to be closed by the integration pass.

*Closed.* The integration pass drew all 113 sheet pins and wired every cross-block net on
2026-09-03. The deviation from `schematic-style` is over: the top sheet is now the block
diagram, wired. See DEC-0022 and `docs/decisions/actuator-sch-integrate.md`.

### DEC-0010 - One AFE design serves both V50N and V10N
**Date** 2026-09-02 · **Status** Accepted · **Scope** `loadcell_afe`

No build variant in the load cell front end. Only the load cell part differs between V50N and
V10N.

*Reasoning.* Both variants use the same HBK S2M family at the same 2 mV/V sensitivity and the
same 5 V excitation (`REQ-FF-09..11`), so the full-scale bridge output is ± 10 mV in both cases
(`CALC`). The ADS1235 at gain 128 has 167 % / 208 % noise headroom against the V50N / V10N
noise specs from a single configuration. The variants differ in *newtons per volt*, which is a
calibration constant, not a circuit change.

*Consequence.* Variant handling lives in the calibration data in `nvm_calibration`. Note that
`REQ-SF-03` (peak current limit "configurable per variant") is a **separate** matter in
`motor_drive` — see OQ-08.

### DEC-0011 - Motor FET temperature belongs to `motor_drive`; `VBUS_MON` provisionally does too
**Date** 2026-09-02 · **Status** Accepted (VBUS_MON provisional) · **Scope** `motor_drive`,
`temp_sense`, `mcu`

`MOTOR_FETTEMP` (PA4, internal ADC) is a `motor_drive` net. `temp_sense` owns **only** the two
precision ADS1120 channels of `REQ-EL-07` (load cell, encoder rail mid-point).
`VBUS_MON` (PC5) is provisionally allocated to `motor_drive` as the inverter DC-link monitor.

*Reasoning.* Two "temperature" things on this board are unrelated: a coarse thermal-protection
reading of the power stage, and a 1 °C-accurate measurement for force/position compensation.
Naming both "temperature sensing" would put one block's parts in another block's sheet.
For `VBUS_MON`: the USB3320 already reports VBUS state to the MCU over ULPI, so a separate MCU
ADC channel for USB VBUS would be redundant, whereas a DC-link monitor is genuinely needed by
the motor control loop and by `REQ-SF-03`. The block diagram supports this — it labels the
motor drive "Phase current, VBUS sense".

*Escalation.* `VBUS_MON` is flagged as **OQ-01** for captain confirmation rather than escalated
as a blocker: the alternative reading changes only which sheet holds one divider, which is
cheap to move.

### DEC-0012 - Limit switches get a hardware brake path in addition to the firmware kill
**Date** 2026-09-02 · **Status** Accepted · **Scope** `ui_io`, `motor_drive`

`LIMIT_nBRK` (PE6) drives `TIM1_BKIN2`, forcing the PWM outputs to their inactive state in
hardware. This is **in addition to** the firmware kill of `REQ-SF-02`, not a replacement.
`DRV8323_nFAULT` (PE15) drives `TIM1_BKIN` on the same principle.

*Reasoning.* `SPEC §9.1` asks only for "firmware to kill motor drive in the case of limit
switch actuation". Both the block diagram ("Limit Switches … BREAK input") and the `.ioc`
(`LIMIT_nBRK` → `TIM1_BKIN2`, `BreakState=TIM_BREAK_ENABLE`) show the stronger hardware path.
A hardware break does not depend on firmware being alive, scheduled, or correct — for a stage
that can drive a probe into a load cell, that is the right side to err on.

*Consequence.* Recorded as `REQ-SF-05` / `REQ-SF-06`. The break nets are cross-block
safety-critical signals: see `ARCHITECTURE.md §5`. Their polarity and drive type must not be
changed by one block alone. Bring-up step 8 of `TEST_PLAN.md` tests this before the motor is
ever energised under load.

### DEC-0013 - MCU pinned to the STM32H723VET6 from the captain's CubeMX file
**Date** 2026-09-02 · **Status** Accepted · **Scope** `mcu`, all blocks

`hardware/cubemx/ARIA_SRB_FAFF_2_POC_CBs_1.ioc` (CubeMX 6.17.0, `Mcu.Name=STM32H723VETx`,
`Mcu.CPN=STM32H723VET6TR`, LQFP100, 77 pins allocated) is committed to the repo and is **the
authority** for every MCU-side pin assignment and net name.

*Reasoning.* Supplied by the captain as the starting point; corroborated by the block diagram
("STM32H723"). Every block interface in `ARCHITECTURE.md §3.2` is quoted from it so that block
workers do not need CubeMX open.

*Caveats for block workers.* (a) The clock tree in the `.ioc` is untouched CubeMX default —
PLL from HSI, SYSCLK 64 MHz — and is **not** a designed clock tree; it will change. (b)
`PH0-OSC_IN` is set to *HSE external clock source* with `PH1-OSC_OUT` unallocated, so HSE must
be a driven clock, not a bare crystal (OQ-03). (c) Some nets the schematic needs have no pin
yet (EEPROM `nWP`, rail PGOOD/enable) — OQ-06, OQ-07. Spare pins exist.

### DEC-0014 - The load cell interface supports both 4-wire and 6-wire
**Date** 2026-09-02 · **Status** Accepted · **Scope** `loadcell_afe`

The load cell connector and AFE accommodate a 4-wire **or** a 6-wire bridge connection.

*Reasoning.* The block diagram states "4 or 6 wire" for the HBK S2M. The specification design
log is emphatic that 6-wire Kelvin sensing is what makes the accuracy budget reachable
("6-wire bridge where we can Kelvin sense to mitigate against V drop in the leads"), and the
S2M is a six-wire part. Supporting both costs two connector positions and two sense inputs;
refusing 4-wire would rule out substitute load cells during PoC bring-up, which is contrary to
the "load cell agnostic" intent of the dev-board build (`SLOG`).

*Consequence.* Provide the sense lines with a documented link option to tie them to the
excitation lines locally for a 4-wire cell. Default build is 6-wire.

### DEC-0015 - The Amodo house library is bound through `${AMODO_KICAD_LIB}`
**Date** 2026-09-02 · **Status** Accepted · **Scope** repo

Project-level `sym-lib-table` (29 `Amodo_*` symbol libraries) and `fp-lib-table` (the `Amodo`
footprint library) live in `hardware/kicad/faff2_cbs1/` and reference the library through the
`${AMODO_KICAD_LIB}` path substitution variable.

*Reasoning.* Captain instruction. The library lives at `C:\Amodo\AmodoKiCadLib` on the
captain's Windows KiCad and `/mnt/c/Amodo/AmodoKiCadLib` from WSL. A path variable is the only
way one committed table opens correctly on both. Project-level tables (rather than each
engineer's global table) mean the project is self-describing.

*Note.* The Amodo footprints already reference 3D models through a **second** variable,
`${AMODO_3D}`, so both must be set. `README.md` documents how each side sets them.

*Rule for the whole project.* Prefer existing Amodo parts. Create a new part **only** where
absolutely necessary, and create it in the Amodo library itself — never scattered in this repo.
During parallel block work, report any new-part addition in a status line so firstmate can
serialise concurrent edits to the same category file. Recorded in `AGENTS.md`.

*Already available, do not recreate:* `ADS1235` exists in `Amodo_ADCs.kicad_sym`. Check the
library before drawing any part.

### DEC-0016 - The skeleton was machine-generated once; the generator is not committed
**Date** 2026-09-02 · **Status** Accepted · **Scope** repo

The eleven `.kicad_sch` files were produced by a one-shot Python generator (deterministic
UUIDs via `uuid5`), which is **deliberately not** committed.

*Reasoning.* Once block workers start editing sheets in KiCad, re-running the generator would
silently destroy their work. A tool whose only safe moment has already passed is a hazard in
the repo, not an asset. From here the schematics are hand-maintained in KiCad.

### DEC-0017 - KiCad 9 only
**Date** 2026-09-02 · **Status** Accepted · **Scope** repo

All schematic and PCB work uses KiCad 9 (`kicad-cli` 9.0.8 here). Files are written at
schematic format version `20250114`. No other KiCad major version may open or save these files.

*Reasoning.* Brief mandate. Practically: opening a KiCad 9 project in KiCad 8 fails, and saving
from a newer version would silently migrate the format for everyone else.
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

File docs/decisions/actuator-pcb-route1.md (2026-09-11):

# PCB routing round 1 — `faff2_cbs1.kicad_pcb`

Layout phase, step 3. Placement round 1 was reviewed and approved ("This looks
good"), which clears house gate **G7**, so this is the first routing pass on the
board. It is submitted for the captain's routing review; comment rounds follow.

The board file is the master. Every tool below **mutates** it — none regenerates
it, and `tools/gen_pcb_setup.py` / `tools/gen_pcb_rules.py` must never be run
over it again.

KiCad 9 only — `kicad-cli` 9.0.8, board format `20241229`.

---

## 1. Stage order taken

The house process (`pcb-layout-style`, VanClock 2026-07-30) routes in five
gated steps, ground first. That order is followed, with the later stages split
where the block needed its own treatment.

| # | Stage | Tool | What landed |
|---|---|---|---|
| 1 | GND planes | `route1_zones.py` | `In1.Cu` + `In2.Cu` poured whole, 0.15 mm/0.15 mm, 0.25 mm fillet, islands removed, thermal reliefs (internal layers only) |
| 2 | Decoupler positive feeds | `route2_decoupling.py` | feed via → cap pad → IC pin, never pin-first |
| 3 | GND, one via per pad | `route3_gnd.py`, `route3b_gndfix.py` | every SMD GND pad its own via; completeness proof in §5 |
| 4 | Power distribution | `route4_power.py`, `route4b_powervias.py`, `route4c_widen.py`, `route4d_renarrow.py` | the rails joined up, via counts sized from the 1.0 A budget, widths from the current |
| 5a | USB HS pair | `route9_usb.py` | drawn by hand, not routed — §3 |
| 5b | DRV8323 interface | `route8_drv.py` | Kelvin taps first, then gates — §4 |
| 5c | Critical classes | `route5_critical.py --stages rs422,analog,rf,clocks` | RS-422 pairs, the analog corridor, the 50 Ω sync chain, the clocks |
| 6 | General signal fill | `route6_signals.py` | everything else, shortest span first |
| 7 | G5 stitching | `route7_stitch.py` | a GND via beside every signal via |

`route5_critical.py` now takes `--stages`; its `bridge` and `usb` stages are
superseded by 5a/5b and do not run by default. Re-running them would undo
better work, which is exactly what the flag exists to prevent.

---
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

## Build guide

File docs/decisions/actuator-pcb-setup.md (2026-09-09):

# PCB board setup — `faff2_cbs1.kicad_pcb`

Layout phase, step 1: board infrastructure only. **No component placement** — placement is
the next task and is gated on captain review (house guideline G7). Everything imported from
the schematic sits in a holding grid off-board, grouped by sheet.

Built by `tools/gen_pcb_setup.py` (board) and `tools/gen_pcb_rules.py` (net classes + DRC).
From placement onwards the board file is the master; do not re-run the generator over it.

KiCad 9 only — `kicad-cli` 9.0.8, board format `20241229`. AGENTS.md has the hard rule.

---

## 1. Captain's rulings, and where each one landed

| Ruling | Where it lives |
|---|---|
| JLCPCB standard 4-layer, stackup verified from JLC's published table (`JLC04161H-7628`) | `(setup (stackup …))` in the board — §2, **superseded by §2a** |
| Round 2: six layers, SIG/GND/PWR/PWR/GND/SIG, power off the signal layers | `JLC06161H-7628` — §2a |
| House G1: outer layers carry **all** signals **and** power as traces; both inner layers unbroken GND | layer roles in the board — §2 |
| Via 0.6 mm pad / 0.20 mm drill, no-surcharge JLC drill, reaches the recommended 0.20 mm annulus | single via definition in every net class — §3 |
| **1.0 A per via**, *not* the old 3 A figure — JLC plates ~18 µm | §3, with the derivation |
| Trace/space 6/6 mil default, wider for power | `Default`/`Signal` net class 0.1524 mm — §6 |
| Dev board, size unimportant, generous but sensible; M3 corner holes, rounded corners | 210 × 130 mm, R2, 4 × M3 — §4 |
| Actuator connectors on one side; bench connectors on the other | §5 — the placement task executes it |

---

## 2a. Stackup, round 2 — JLCPCB `JLC06161H-7628` (6 layers)

**Superseded §2 on 2026-09-09.** The captain, reviewing routing round 1:
*"The PCB looks to be pretty un-routed still. Can you press on and keep going?
If needed, remove all power connections, and only route signals for now. Then,
we can add two additional internal layers and use these for routing power."*

That authorises six layers, arranged **SIG / GND / PWR / PWR / GND / SIG**:

| # | Layer | Role | Material | Thickness mm | Dk |
|---|---|---|---|---|---|
| — | F.Mask | — | solder mask | 0.010 | |
| L1 | **F.Cu** | `mixed` — signals | copper 1 oz | 0.0350 | |
| — | dielectric 1 | prepreg | NP-155F **7628** | **0.2104** | **4.40** |
| L2 | **In1.Cu** | `power` — GND Plane L2, unbroken | copper 0.5 oz | 0.0152 | |
| — | dielectric 2 | core | NP-155F Core | 0.4000 | 4.36 |
| L3 | **In2.Cu** | `power` — PWR Plane L3, power routing | copper 0.5 oz | 0.0152 | |
| — | dielectric 3 | prepreg | NP-155F 7628 | 0.2104 | 4.40 |
| L4 | **In3.Cu** | `power` — PWR Plane L4, power routing | copper 0.5 oz | 0.0152 | |
| — | dielectric 4 | core | NP-155F Core | 0.4000 | 4.36 |
| L5 | **In4.Cu** | `power` — GND Plane L5, unbroken | copper 0.5 oz | 0.0152 | |
| — | dielectric 5 | prepreg | NP-155F 7628 | 0.2104 | 4.40 |
| L6 | **B.Cu** | `mixed` — signals | copper 1 oz | 0.0350 | |
| — | B.Mask | — | solder mask | 0.010 | |

Total **1.582 mm** including mask — JLC's 1.6 mm class.

**House G1's substance is preserved, not waived.** G1 exists so that every
signal is referenced to a solid plane; here every outer-layer signal still
faces an unbroken ground plane 0.2104 mm below it, which is the same reference
distance the 4-layer build gave. What changes is that power no longer has to
share the signal layers, which is the whole point of the ruling.

**Why `-7628` of JLC's ten 6-layer options.** Its outer prepreg is *identical*
to the 4-layer board's — 7628 glass, 0.2104 mm, Dk 4.40 — so every impedance
number already derived and already routed carries over untouched: the USB pair
stays **0.30 mm on a 0.20 mm gap for 90.6 Ω**, `SYNC_TRIG` and the two U.FL
inputs stay **0.37 mm for 50 Ω**, and round 1's hand-drawn pair does not have
to be redrawn. The alternatives all move the reference plane closer and would
have forced both geometries to narrow: `-1080` at 0.0764 mm, `-3313` at
0.0994 mm, `-2116` at 0.1164/0.1270 mm.

Same copper weights and the same no-surcharge class as before: 1 oz outer,
0.5 oz inner. Materials Nan Ya NP-155F throughout.

*Source.* JLCPCB's published impedance-template data, `templateName`
`JLC06161H-7628`, 6-layer 1.6 mm, 1 oz outer / 0.5 oz inner. As in §2, JLC's
own impedance calculator is the arbiter before fab.

Applied by `tools/gen_pcb_stack6.py`. The second ground plane moved from
`In2.Cu` to `In4.Cu` with it.

---

## 2. Stackup — JLCPCB `JLC04161H-7628` (4 layers, superseded by §2a)

4-layer, 1.6 mm nominal, 1 oz outer / 0.5 oz inner. This is JLC's default no-surcharge
4-layer build.

| # | Layer | Role (KiCad class) | Material | Thickness mm | Dk | Df |
|---|---|---|---|---|---|---|
| — | F.Mask | — | solder mask | 0.010 | | |
| L1 | **F.Cu** | `mixed` — SIG + PWR Top | copper 1 oz | 0.0350 | | |
| — | dielectric 1 | prepreg | NP-155F 7628×1 | **0.2104** | **4.4** | 0.02 |
| L2 | **In1.Cu** | `power` — GND Plane L2 | copper 0.5 oz | 0.0152 | | |
| — | dielectric 2 | core | NP-155F core | 1.0650 | 4.43 | 0.02 |
| L3 | **In2.Cu** | `power` — GND Plane L3 | copper 0.5 oz | 0.0152 | | |
| — | dielectric 3 | prepreg | NP-155F 7628×1 | **0.2104** | **4.4** | 0.02 |
| L4 | **B.Cu** | `mixed` — SIG + PWR Bottom | copper 1 oz | 0.0350 | | |
| — | B.Mask | — | solder mask | 0.010 | | |

Total 1.6062 mm including mask; 1.5862 mm copper-to-copper, which is what JLC calls "1.6 mm".
Copper finish ENIG.

*Sources.* The geometry is JLCPCB's own impedance-template data (`templateName`
`JLC04161H-7628`: top copper 0.035, prepreg `7628*1` 0.21040, core 1.065 with 0.0152 inner
copper, symmetric) — it carries **no** dielectric constants. Dk/Df are the Nan Ya **NP-155F**
values JLC's templates call up. JLC's public impedance page prints a generic "4.6" for the
core; the NP-155F figure of 4.43 is used here instead, and it is electrically irrelevant
anyway — the core sits between two GND planes and no signal crosses it.

**Only the 0.2104 mm prepreg matters for impedance**, because L2/L3 are solid GND and every
trace is on an outer layer (G1/G4). Reference plane for F.Cu is In1.Cu; for B.Cu, In2.Cu.

### Impedance-relevant geometry (F.Cu over In1.Cu, H = 0.2104 mm, Dk 4.4, t = 0.035 mm)

| Target | Geometry | Modelled |
|---|---|---|
| 50 Ω single-ended microstrip | **W = 0.37 mm** | 50.0 Ω (Hammerstad–Jensen); IPC-2141 gives 0.35 mm |
| 90 Ω differential (USB 2.0 HS) | **W = 0.30 mm, S = 0.20 mm** | 90.6 Ω, i.e. +0.6 % — spec allows ±15 % |

These are closed-form estimates (Hammerstad–Jensen with thickness correction, cross-checked
against IPC-2141). **JLC's own impedance calculator is the arbiter before fab** — if the board
is ever ordered with impedance control, re-check there and adjust the net-class widths.

Nets that want them: `/mcu/USB_DM` + `/mcu/USB_DP` (90 Ω diff); `/mcu/SYNC_TRIG` to the SMA
`J902`, and `Net-(J503-In)` / `Net-(J504-In)` to the two U.FL jacks (50 Ω).

---

## 3. Via definition and the current budget

**One via for the whole board: 0.6 mm pad / 0.20 mm drill** → annular ring **0.20 mm**, which
is exactly JLC's *recommended* figure (their absolute minimum is 0.15 mm). 0.20 mm is a
no-surcharge drill; JLC's multilayer minimum is 0.15 mm.

**1.0 A per via.** Derivation, using JLC's published average hole plating of **18 µm**:

```
barrel copper area = π · 0.20 mm · 0.018 mm = 0.0113 mm²
equivalent 1 oz (35 µm) trace width = 0.0113 / 0.035 = 0.323 mm
IPC-2221 external, 10 °C rise, 0.323 mm  ->  1.05 A
```

So 1.0 A/via is the 10 °C-rise capacity with a hair of margin. **The old 3 A figure is wrong
by about 3×** — it assumes a much heavier barrel than JLC actually plates. Size every power
via count from 1.0 A: `n = ceil(I / 1.0)`, minimum 2 on any rail that changes layer.

Worked numbers for this board: 25 W peak at 24 V (`REQ-EL-03`) is 1.04 A → **2 vias**; motor
phases at an assumed 3 A peak → **3 vias**.

Trace capacity on 1 oz outer copper (IPC-2221 external), for reference at routing:

| Width mm | 10 °C rise | 20 °C rise |
|---|---|---|
| 0.152 (6 mil) | 0.61 A | 0.83 A |
| 0.30 | 1.00 A | 1.36 A |
| 0.50 (G3 power) | 1.45 A | 1.96 A |
| 1.00 (motor) | 2.39 A | 3.24 A |

No blind, buried or micro vias — JLC's standard 4-layer process is through-via only, and the
DRC constraints forbid them.

---

## 4. Board outline and mounting

**210 × 130 mm**, external corners radiused **R2** (house rule: always radius, 2 mm typical).
Origin on the A2 page at (30, 30); drill/place origin at the board's bottom-left corner.

*Why 210 mm wide.* The width is set by the actuator connector edge, not by area. Those nine
connectors are 149.2 mm of body; at ~5 mm apart that is 189 mm, plus 11 mm at each end to
clear the corner mounting holes' 5.5 mm keepouts → 211 mm. Area is not the constraint: 408
footprints total 6562 mm² of courtyard, so 27 300 mm² of board is ~24 % utilisation — generous,
as instructed, and it leaves real room for probe access and the block-to-block routing
corridors G7 wants.

*Mounting holes.* Four **M3 NPTH**, `Amodo:MountingHole_3.2mm_M3_NO-PAD_NPTH`, centres 6 mm in
from each edge — (6,6), (204,6), (204,124), (6,124) in board coordinates. That footprint
already carries a 5.5 mm keepout (no tracks, vias, pours or footprints), which is the
screw-head courtyard the house rules ask for. They are `BOARD_ONLY | EXCLUDE_FROM_BOM |
EXCLUDE_FROM_POS_FILES`, so schematic parity does not see them as extra parts.

**Non-plated, deliberately.** Plated holes tied to GND would ground the board to the bench
through every metal standoff, giving the precision load-cell AFE a multi-point chassis return.
NPTH keeps the ground reference single-point and under the design's control. Reopen this if
the board is ever put in a shielded enclosure that needs chassis bonding.

---

## 5. Edge plan

The captain's rule: peripherals live near what they cable to — *"all connectors to actuator
(motor, encoders, etc.) on one side"*. The two long edges split accordingly. **The placement
task executes this; nothing below is placed yet.**

**Actuator edge — the 210 mm edge (9 connectors, 149.2 mm of body):**

| Ref | Part | mm | What |
|---|---|---|---|
| `J1103` | Molex Micro-Fit 1×3 | 13.8 | motor phases U/V/W |
| `J1101` | 1×6 2.54 THT | 16.0 | rotary encoder / halls A |
| `J1102` | 1×6 2.54 THT | 16.0 | rotary encoder / halls B |
| `J601` | Hirose FH12-10S FPC | 11.0 | linear encoder (IKP11 read head) |
| `J602` | Samtec FTSH-105 2×5 | 8.4 | linear encoder, second interface |
| `J501` | Phoenix 1729076 8P 5 mm | 41.0 | load cell |
| `J701` | Push-in 4-way 3.5 mm | 15.1 | temp sensors A |
| `J702` | Push-in 4-way 3.5 mm | 15.1 | temp sensors B |
| `J903` | JST XH 4-way | 12.8 | limit switches |

**Bench edge — the opposite 210 mm edge (5 connectors, 68.6 mm of body, lots of slack):**

| Ref | Part | mm | What |
|---|---|---|---|
| `J201` | KYCON KPJX-4S | 16.0 | 24 V power entry (right-angle, latching) |
| `J1001` | USB-C receptacle | 13.0 | USB data (no PD, no bus power) |
| `J902` | SMA jack THT | 9.5 | sync/trigger |
| `J1003` | Samtec SHF-107 14-way | 17.2 | SWD + USART3 debug |
| `J1002` | TSW-105 2×5 THT | 13.0 | bring-up header (**DNP**) |

**Inboard, on the top face:** the three logic-analyser headers `J502`, `J603`, `J703`
(8510-4500PL, 20.5 × 9 mm each) sit inboard with clip clearance around them, near the blocks
they observe (load cell AFE, linear encoder, temp sense) rather than on an edge. Likewise the
44 Keystone test loops, 24 test pads and 9 dual test points stay with the nets they observe —
producer-owns-the-break, DEC-0007.

Keep the 24 V/motor power chain and the switching regulators away from the load-cell AFE
corner; the analog block wants the quiet end of the board, furthest from `J201`, the inductors
and the DRV8323.

---

## 6. Net classes and DRC constraints

All in `faff2_cbs1.kicad_pro` (net classes and DRC floors live in the project file, not the
board). Every class shares the one via definition, 0.6/0.20.

| Class | Track mm | Clearance mm | Applies to |
|---|---|---|---|
| `Default` | 0.1524 | 0.1524 | everything unmatched, incl. `GND` |
| `Motor` | 1.00 | 0.1524 | `MOTOR_U/V/W`, `V24_MOT`, `VM_DRV` |
| `RF50` | 0.37 | 0.1524 | `SYNC_TRIG`, the two U.FL inputs |
| `USB_HS` | 0.30 | 0.1524 | `USB_DM`/`USB_DP`; diff pair 0.30 / 0.20 |
| `Power` | 0.50 | 0.1524 | all rails: 24 V chain, +6V0, +5V, +5VA, +3V3, +3V3A, +3V3_USB, +1V8_USB, +5V_ENC, VENC |
| `Analog` | 0.25 | 0.1524 | bridge and RTD inputs, references, load-cell and temp terminal blocks, `ENC_VREF` |
| `Signal` | 0.1524 | 0.1524 | general signals |

**Every class keeps the 6 mil clearance, deliberately.** The first cut gave `Motor` and
`RF50` 0.30 mm and `Analog`/`Power` 0.20–0.25 mm, and DRC rejected it on the *pads*, before a
single track existed: at 0.5 mm pitch the LQFP100's pads sit 0.20 mm apart and the DRV8323 and
ADS1235 QFN pads 0.25 mm apart, so any class clearance above that fails on the package itself.
A class clearance has to be satisfiable by the finest-pitch pads carrying that class's nets.
**Generous spacing between these nets is routing discipline, not a class constraint** — keep
motor phases, the SW nodes and the analog sense chains well apart when routing, and widen
locally per G1c.

DRC constraints — G12 floors where the house is stricter than JLC, JLC's capability sheet
where it binds:

| Constraint | Value mm | Source |
|---|---|---|
| min track width | 0.15 | G12 floor (JLC allows 0.09 at 1 oz) |
| min clearance | 0.15 | G12 floor |
| min via diameter | 0.60 | the single via definition |
| min through-hole diameter | 0.20 | our via drill is the smallest hole on the board |
| min annular ring | 0.20 | JLC "recommended 0.20 or above" |
| min hole-to-hole | 0.45 | JLC PTH figure (their via-to-via allowance is 0.20) |
| min hole clearance | 0.25 | |
| copper to board edge | 0.30 | JLC needs ≥ 0.20; margin for the router |
| blind/buried and micro vias | forbidden | JLC standard 4-layer is through-via only |

Silkscreen clearance is left at 0 for now — silk tidy-up belongs to the placement gate, and
turning it on here would only report grazes inside library footprints that no placement
decision can fix.

---

## 7. Deliberately not done in this step

- **No placement.** G7 is a hard gate: the captain reviews placement before any routing, so
  placement is its own task. The 408 imported footprints sit in an off-board holding grid,
  grouped by schematic sheet with a caption per group on `Cmts.User`.
- **No GND plane zones.** Establishing the two inner-layer pours is *routing step 1* in the
  house process, and each routing step is opened and closed by the engineer. Defining them now
  would only mean stale fills through the whole placement round.
- **No routing, no zones, no test-point relocation.**
- **No `docs/DECISIONS.md` entry.** The task brief scoped this to one lightweight decisions
  file; the DEC-numbered register entries for these rulings are still owed.

## 8. DRC state, and two findings to escalate

`kicad-cli pcb drc --severity-all --schematic-parity`, KiCad 9.0.8:

**Schematic parity 0.** 408 footprints, every reference, value, footprint id and DNP flag
matching the schematic, every footprint carrying its `/sheet-uuid/symbol-uuid` path. The four
mounting holes are `BOARD_ONLY` and correctly invisible to parity.

**499 unconnected items** — the entire ratsnest. The board carries **0 tracks, 0 vias and 0
zones**, so by construction every net is unrouted; 499 is KiCad's own ratsnest count for that
state, and it is the expected residual until routing. (It is lower than a naive
pads-minus-nets figure because KiCad merges physically overlapping same-net pads — the QFN
exposed-pad arrays and dual test points — and counts spanning-tree edges.)

**77 violations, in four groups. None is a placement or wiring defect:**

| n | Type | What it is |
|---|---|---|
| 40 | `silk_overlap` | reference-designator text colliding between neighbours **in the holding grid**, at the 2.5 mm cell gap. Every item is a `Reference field`. Dissolves at placement |
| 18 | `text_height` | library footprints whose reference or user text is under the 0.8 mm rule (9 references, 9 footprint texts — `U501`, `D303`, `D901`, several test points) |
| 9 | `items_not_allowed` | **escalate** — see below, `Q201` |
| 6 | `lib_footprint_mismatch` | `H1`–`H4` differ from the library by the deliberate `BOARD_ONLY` attributes; `J201` and `J1001` differ only because **KiCad itself normalises an NPTH pad's `F&B.Cu` layer set to `*.Cu`** when the footprint lands on a 4-layer board. Reproduced with a bare load-and-save, no edits — it is KiCad's round-trip, not ours |
| 4 | `annular_width` | **escalate** — see below, `U501` |

An earlier cut had 19 `clearance` violations and 33 parity issues; both are fixed, not
suppressed — see §6 for the clearance cause, and the BOM-flag note below.

*The parity fix.* KiCad takes "exclude from BOM" and DNP from the **symbol**, not from the
library footprint. Several Amodo test-point and test-loop footprints carry `exclude_from_bom`
in the library while their symbols do not, which is 33 parity mismatches. The importer now
clears the footprint flag wherever the schematic does not set it — the schematic is the
authority.

### Escalation 1 — `Amodo:VQFN RHB 32 5x5 mm 0.5 pitch` EP thermal vias are under-annulused

`U501` (ADS1235) has four PTH thermal vias in its exposed pad at **0.5 mm pad / 0.25 mm
drill → 0.125 mm annular ring**. That is below JLC's *recommended* 0.20 mm and below their
**absolute minimum of 0.15 mm**. Via-in-pad on a QFN EP is the standing house exception (G9),
so the vias themselves are fine — the annulus is not. Either the library footprint's EP vias
grow to 0.6/0.20 like every other via on this board, or the captain accepts the deviation
with JLC. **Not waived here.**

### Escalation 2 — `Amodo:DMP4013LFG7` keepout excludes its own pads

`Q201`'s footprint contains a keepout zone with `pads not_allowed` that overlaps the
footprint's own pads 1, 4 and 5 — 9 violations. A keepout meant to hold *other* parts off
applies to the host footprint's pads too. This is a library defect, not a layout one; it will
follow `Q201` everywhere it is used until the house library is fixed.

Both are library issues in read-only `AmodoKiCadLib`, which is not ours to modify — they are
recorded here for the captain to fix upstream.

## 9. Bring-up-relevant notes

- Drill/place origin is the board's **bottom-left corner** — pick-and-place and drill files
  will be relative to it.
- Nine parts are DNP and carry the `FP_DNP` attribute on the board, so they are fitted with
  real footprints and land normally: `R506`, `R507`, `R521`, `D602`, `R708`, `R709`, `J1002`,
  `R1001`, `R1107`. Assembly variants handle population — never delete them.
- The three logic-analyser headers and the 44 test loops need clip and probe access with the
  board on its jig; that is a placement requirement, not a nicety.

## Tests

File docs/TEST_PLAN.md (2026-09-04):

# FAFF 2 CBs_1 - Test and Bring-Up Plan

The CBs_1 proof-of-concept is a **larger, development-board-style build that precedes
miniaturisation** (`REQ-AR-17`). Its job is to retire electronics risk fast, not to fit the
final mechanical package. Every design choice below trades board area for testability, and
that trade is deliberate.

This is house doctrine, not just a project preference — the EEE Hardware Design Standard draft
(`docs/HardwareDesignStandard_DRAFT/`) says it independently: "If your PCB is very space
constrained, and timelines allow, then you should consider making a 'big' first revision of the
board… Once you have proved the hardware, you can then miniaturise at a later date."

**Governing principle: every block must be independently testable.** A block that can only be
tested with the whole board working is a block that will be debugged last and slowest.

---

## 1. Process requirements

Before the board is ordered, not after.

| # | Requirement | Source |
|---|---|---|
| 1.1 | A firmware engineer reviews the schematic before fabrication. "If a board has a µC, probably shouldn't order without a firmware [engineer] at least reviewing the project so far." | Design Standard, *Designing Something with a Microcontroller* |
| 1.2 | Firmware development starts in parallel on a dev board, not when the PCB lands. FAFF 2 has timing-critical interfaces (TIM1 PWM + break, three quadrature decoders, 4800 SPS streaming), which is exactly the case the standard calls out. | Design Standard; `SLOG` (FAFF 1 close report: "Onboard SW/FW from the start") |
| 1.3 | The `.ioc` is maintained as the single pin-map authority and re-committed whenever it changes. Any schematic change that needs a new MCU pin goes through the `.ioc` first. | DEC-0013 |
| 1.4 | Every board built gets a serial number and an entry in a Notion hardware-tracking database recording build state, tests done, and every modification. | Design Standard, *Keeping Track of Hardware* |

## 2. Test point strategy

### 2.1 Type selection

From the AmodoKiCadLib, chosen per net rather than by default (DEC-0018):

| Part | Use for | Do not use for |
|---|---|---|
| `TestPoint` | 1.0 mm SMT pad. DC rails and static pin states checked with a DMM. | Anything you will scope — needs a wire soldered on. |
| `TestPointHook` | THT loop. Nets you will attach a scope probe or logic analyser to: I2C, SPI, GPIO, fault lines. | Nets where ringing/overshoot must be measured accurately. |
| `TestPointDual` | THT, signal hole plus a spring-ground hole. Nets where **signal integrity matters** — small measurement loop, minimal probe inductance, low magnetic pickup. | Where space genuinely forbids it. |

Where `TestPointHook` is used, place **GND hooks alongside** so the scope ground clip has
somewhere to go. Prefer through-hole test points generally, per the standard.

### 2.2 Where test points are forbidden

**No test points on the ULPI bus or the OCTOSPI/QSPI bus.** The standard: test coverage on
very high speed interfaces adds stub capacitance and an impedance discontinuity, and a
conventional passive probe will load or distort the signal. ULPI runs a 60 MHz clock with
single-digit-nanosecond edges; QSPI is comparable. This **overrides** the general "test point
on every key signal" rule for these two buses. DEC-0018 ruling 1.

If one of these ever must be observed, that is a job for a switched coaxial connector and an
active probe, not a hook — and we do not currently own a suitable active probe.

### 2.3 Coaxial access

Nets we expect to scope or inject into repeatedly get a coaxial connector rather than a test
point, so test gear connects with a stock cable:

- **SYNC/TRIGGER** — already an SMA jack by specification (`REQ-EL-06`).
- **Load cell bridge output** (`SIG+`/`SIG-`) — strong U.FL candidate. This is the net whose
  noise floor decides whether `REQ-FF-04` is met, and it will be measured many times.
- **A motor phase node and the DC link** — U.FL candidates for switching-waveform work.

U.FL is probed with the U.FL-to-BNC adapter cable stocked in the EEE lab.

## 3. Rail test points, isolation links and current breaks

Ownership follows the **producer-owns-the-break** rule (DEC-0007): the block that generates a
rail owns its test point, isolation link and current break.

### 3.1 Required per rail

Every supply rail on the board gets **all three**:

1. **A test point** on the rail, close to its point of use, not just at the regulator.
2. **An isolation link** — 0R link, jumper or solder bridge — so the rail can be brought up,
   or a downstream block cut loose, independently.
3. **A current-measurement break** — a series link that can be replaced by a current meter or
   a known shunt, so each block's consumption is measurable against the `CALC` power budget.

The standard mentions 0R links for power measurement as a practice its author personally
skips. The brief for this build **requires** them, and the brief outranks the standard
(DEC-0018). They stay: the whole point of a dev-board revision is measuring what you assumed.

### 3.2 Rail inventory

Settled by the block wave; the structure below is what is actually drawn. `power_rails` feeds
its logic branch from **`V24_LOGIC`**, a second protected branch out of `power_entry_24v`
independent of the motor branch, so the motor stage can be left dead while logic is brought up.

| Rail | Source block | Feeds | Break / link | Budget check against `CALC` |
|---|---|---|---|---|
| `+24V_IN` | `power_entry_24v` | (pre-protection) | — | 25 W peak, 7 W typical |
| `+24V_SW` | `power_entry_24v` | `motor_drive` only | `R203` | motor Iq 20 mA quiescent |
| `V24_LOGIC` | `power_entry_24v` | `power_rails` | `R204` | logic branch, ~5.8 W in |
| `+6V0` | `power_rails` | pre-regulator for `+5V` / `+5VA` | `R305` | 6.110 V nominal, sheet-local, never leaves `power_rails` (`DEC-P10`) |
| `+5V` | `power_rails` | IKP11 read head | `R306` | ~115 mA |
| `+5VA` | `power_rails` | ADS1235 AVDD + bridge excitation, ADS1120 AVDD | `R307` | ~30 mA |
| `+3V3` | `power_rails` | STM32, USB3320, DRV8323 logic, QSPI, EEPROM | `R312` | ~1.1 A |
| `+3V3A` | `power_rails` | MCU VDDA / VREF+, ADS1235 and ADS1120 DVDD | `FB301` | ~10 mA |

### 3.3 Block isolation

**What the block wave actually drew**, reconciled at integration. The original plan here asked
for a rail link from `power_rails` to each consumer block; that is *not* what landed, and the
reason is sound. Every block takes the same global rail net, so per-consumer links inside
`power_rails` would need per-block rail names and would have broken the frozen block contracts.
The rule adopted instead: **`power_rails` owns one break per rail (§3.2), and a block that wants
its own supply break fits a 0R at its own supply entry, inside its own sheet.**

Thirty-two 0R links are drawn across the project. The ones that matter for bring-up:

| Link | Sheet | Opens |
|---|---|---|
| `R203` | `power_entry_24v` | the whole 24 V motor branch — **the one that keeps the actuator dead** |
| `R204` | `power_entry_24v` | the 24 V logic branch into `power_rails` |
| `R305` `R306` `R307` `R312` `FB301` | `power_rails` | one rail each, per §3.2 |
| `R1101` + `R1102` | `motor_drive` | the motor bus at the block, in series with `R203` |
| `R1114` | `motor_drive` | the DRV8323 gate-driver supply `VM_DRV`, leaving the bus up |
| `R1106` / `R1107` | `motor_drive` | rotary-encoder supply select, 3V3 or 5 V |
| `R601` | `linear_encoder` | the 5 V read-head feed — its current break |
| `R1012` | `mcu` | `+3V3_USB` |
| `R506`-`R510` | `loadcell_afe` | the 4-wire / 6-wire build (DEC-0014) |
| `R520` / `R521` | `loadcell_afe` | ADS1235 `CLKIN` source select |
| `R708`-`R711` | `temp_sense` | the 3-wire RTD build on each probe channel |

Signal isolation on the shared buses, so one peripheral can be taken off a bus that will not
enumerate:

| Link | Bus | Takes off |
|---|---|---|
| `R801` / `R802` | I2C1 | the EEPROM, with the bus left pulled up |
| `R1116` / `R1117` | SPI2 | the DRV8323's `SCLK` / `SDI` |

SPI3 has no series link: `loadcell_afe` is the only device on it, so opening the bus and
opening the block's own supply are the same test.

The two **TIM1 BREAK** nets each have their own break — `R1119` on `DRV8323_nFAULT` in
`motor_drive`, `R915` on `LIMIT_nBRK` in `ui_io` — so each trip source can be exercised alone.
These links are safety-relevant: they must be clearly marked on the silkscreen and default to
**fitted**. Both are.

## 4. Per-block test provisions

What each block owns. Block tasks add these while drawing.

| Block | Must provide |
|---|---|
| `power_entry_24v` | TPs on `+24V_IN`, `+24V_SW`, `PGND`; current break on `+24V_SW`; TP on `V24_MON`; reverse-polarity and fuse behaviour testable without downstream load |
| `power_rails` | TP + isolation link + current break per rail (§3); TP on each feedback node; PGOOD TPs if fitted; the consolidated rail probe header `J301`, moved here from `mcu` in review round 4 |
| `mcu` | The SWD + USART3 debug header (block H, `J1003`, now the STM32 14-way IDC part) and the GND hooks for scope clips (K) — test coverage lives on the page it covers, so these are not a sheet of their own. TPs on `NRST`, `BOOT0`, each supply pin group, HSE clock in, MCO2. **No TPs on ULPI or QSPI** (§2.2). USB-C shield/CC access |
| `motor_drive` | TPs on each gate drive output, each current-sense output, `VBUS_MON`, `nFAULT`; U.FL candidate on one phase node and the DC link; link to isolate the gate driver supply; means to spin the motor with the load cell disconnected |
| `loadcell_afe` | TPs on excitation +/-, sense +/-, `SIG+`/`SIG-` (U.FL candidate), ADC reference, `nDRDY`; SPI3 hooks; link to configure 4-wire vs 6-wire (DEC-0014); means to substitute a resistive bridge simulator for the load cell |
| `linear_encoder` | TPs on each RS-422 receiver output (`ENC_A/B/Z`) and on the 5 V read-head supply; termination fitted/removable; header pinout silkscreened; means to inject a quadrature signal without the read head |
| `temp_sense` | TPs on both probe channels and the ADC reference; `J703` carries the whole SPI2 interface on one keyed logic-analyser plug; means to substitute a fixed resistor for each probe |
| `nvm_calibration` | I2C1 hooks (`SCL`, `SDA`) plus GND hooks; `nWP` TP; pull-ups on removable links |
| `ui_io` | TPs on `SYNC_TRIG` (pre- and post- source termination), `LIM_A`, `LIM_B`, `LIMIT_nBRK`, each button and LED net; means to assert each limit switch without the mechanics |

## 5. Bring-up order

Each step is a gate: do not proceed until it passes. **`R203` stays open until step 9** — the
motor branch is dead, so nothing can move, for every step up to and including the safety-
interlock gate.

The logic rails are global (§3.3), so steps 3 onward do not switch blocks on one at a time:
each rail comes up once at step 2 and every consumer on it is live from then on. What is
switched per block is the bus or supply link the block owns, and each step below names it.

| # | Step | Pass criterion |
|---|---|---|
| 1 | **Bare-board and power entry.** 24 V in, all rail links open. Check protection, inrush, fusing. | `+24V_SW` correct; reverse polarity does not damage; no smoke; `V24_MON` reads correctly by DMM |
| 2 | **Rails, one at a time.** With `R203` open (motor branch dead), close `R204`, then one rail break at a time - `R305`, `R306`, `R307`, `R312`, `FB301`. | Each rail within tolerance; ripple acceptable; quiescent current per rail measured at its own break and reconciled against `CALC`; `RAIL_PGOOD` LED `D303` lights and `TP308` reads high |
| 3 | **MCU alive.** `+3V3` and `+3V3A` up. HSE clock present at `TP1003`, reset behaves at `TP1002`, SWD connects on `J1003`. | Debugger attaches; MCO2 output present at the expected frequency; blinky on `LED_1` |
| 4 | **Debug console.** USART3 over the debug header. | Characters out and in at the expected baud |
| 5 | **NVM.** `R801` / `R802` fitted. | EEPROM reads and writes over I2C1; device ID as expected. Lift either link to prove the bus survives the device being removed |
| 6 | **Load cell AFE.** `+5VA` and `+3V3A` up (step 2). Use a resistive bridge simulator before a real load cell. | ADS1235 responds over SPI3; `nDRDY` toggles at 4800 SPS; **measured input-referred noise meets `REQ-FF-04`** with a shorted/simulated bridge. This is the single most important electrical result on the board |
| 7 | **Sensors.** Temperature (§4 substitute resistors) - with `R1116` / `R1117` open the ADS1120 has SPI2 to itself. Then the linear encoder with an injected quadrature signal, then with the real IKP11; meter the read head at `R601`. | ADS1120 reads both channels to `REQ-EL-07`; read-head current inside the `CALC` allowance; TIM5 counts up and down correctly and the Z index lands where expected |
| 8 | **Safety interlocks — before any motor power.** With `R203` still **open**, assert each limit switch and each `nFAULT` source in turn and confirm TIM1 outputs go inactive. Open `R915`, then `R1119`, to exercise each trip source alone. | Both BREAK paths independently force PWM inactive, verified at the gate-drive test points. **Both links refitted before step 9.** Gate for step 9 |
| 9 | **Motor drive, no mechanics.** Configure the DRV8323 over SPI2 with `R1114` open (gate-driver supply down) before closing `R203`; then unplug `J1103` so the motor is **disconnected from the actuator**. Open loop, low duty. | Gate waveforms clean; phase currents read plausibly on all three channels; `VBUS_MON` correct; DRV8323 configures over SPI2 |
| 10 | **Motor on the actuator, no load cell in the force path.** Closed-loop position using the linear encoder; homing against the limit switches. | Homing repeatable; position tracks to `REQ-PS-01..03`; travel stops at both limits |
| 11 | **Full force loop.** Load cell in the path, current limit set per `REQ-SF-03` **before** the first move. | Static force hold within `REQ-FF-03`; current limit trips before 150 % of load cell absolute maximum |
| 12 | **Streaming and sync.** USB enumeration, 4800 SPS stream, SMA trigger output. | Enumerates as high speed; no dropped samples at 4800 SPS (`REQ-CC-03`); SYNC edge correct into 50 Ω |
| 13 | **System characterisation.** Force loop bandwidth, cycle-speed overshoot. | `REQ-ME-06` 40 Hz small-signal; overshoot within `REQ-ME-04`/`05` |

Steps 8 and 11 are the two where a mistake damages the load cell. Neither may be shortcut.

## 6. Records to produce

| Deliverable | Where |
|---|---|
| Serial-numbered build and modification state for every board | Notion hardware-tracking database (Design Standard, *Keeping Track of Hardware*) |
| Measured rail voltages and per-block currents vs the `CALC` budget | Bring-up report, step 2 |
| Measured AFE noise floor vs `REQ-FF-04` | Bring-up report, step 6 |
| Evidence that both TIM1 BREAK paths work | Bring-up report, step 8 |
| Any schematic or layout change found during bring-up | Repo, plus the hardware log |

## 7. What this plan does not yet cover

- **`RAIL_PGOOD` at the MCU.** OQ-07 has still allocated no pin, so power-good is observable
  only at `D303` and `TP308` inside `power_rails` (DEC-0023). Firmware cannot read it.
- **EMC pre-compliance.** `REQ-SC-01` says no formal testing and no CE mark. The Design
  Standard's argument still applies: EMC practice is followed to avoid intra-system problems
  ("an IC's reset pin routed too close to a switchmode supply, causing spurious reset"), not to
  pass a test. Layout-wave concern.
- **Probe-type-specific setups** for the miniaturised revision, which does not exist yet.

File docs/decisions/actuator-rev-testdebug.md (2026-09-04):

# Review revision — dissolving `test_debug`, and the `mcu` / `ui_io` batches

Captain's review pass on the `CBs_1` schematic, 2026-09-03. Three batches landed
together on one branch because they all touch `mcu.kicad_sch`:

| # | Captain's words | Result |
|---|---|---|
| R1 | "Can all of the test_debug page be implemented on the relevant circuits page? I do not like breaking the test coverage out onto its own sheet." | `test_debug.kicad_sch` deleted; its three blocks moved onto `mcu` |
| R2 | "I do not like the shared clock for STM32 and USB phy. Can these have their own crystals?" | The shared 24 MHz fan-out is gone. The PHY gets its own crystal; the STM32 keeps its own oscillator |
| R3 | "This page feels a bit cramped. Feel free to use an A2 sheet if required." | `mcu` is A2 and re-laid |
| R4 | "Net labels look good, but sheet entry / exit flags do not. These should all be right justified, and you will just need to use more horizontal space." | All 47 hierarchical labels on `mcu` are right-justified in clean columns |
| R5 | "more horizontal protection diodes (D903)" · "R907 would also look better horizontal" · "unnecessary vertical resistor placement for R915" | `ui_io`: `R907` and `R915` lie along the signal, `D903` shunts straight down |
| R6 | "LIM_A and LIM_B sheet exit points have overlap. You can stretch this circuit out to the right of the sheet if you need more space." | The two exits are clear of every wire and label |

Files touched: `mcu.kicad_sch`, `ui_io.kicad_sch`, `test_debug.kicad_sch` (deleted),
`faff2_cbs1.kicad_sch` and its generator `tools/gen_root_sheet.py`, `faff2_cbs1.kicad_pro`,
`sym-lib-table`, the new `faff2_passives.kicad_sym`, `AGENTS.md`, `README.md`,
`docs/ARCHITECTURE.md`, `docs/TEST_PLAN.md`, `docs/DECISIONS.md` (one amendment), and this file.

---

## 1. R1 — `test_debug` is dissolved

### D-REV-01 — Test coverage lives on the circuit page it covers, never its own sheet

The `test_debug` sheet held three blocks. All three moved to `mcu.kicad_sch`:

| Was | Is | Refdes |
|---|---|---|
| **T1** SWD + USART3 debug header | **H** on `mcu` | `J401→J1003`, `R401→R1013`, `R402→R1014` |
| **T2** consolidated rail probe header | **`power_rails` block D** | `J402→J1004→J301` (moved off `mcu` in review round 4) |
| **T3** six GND hooks for scope clips | **K** on `mcu`, re-drawn as one row of six | `TP401..406 → TP1006..1011` |
| power symbols | — | `#PWR401..414 → #PWR1051..1064` |

*Why `mcu` for all three.* Block H is unambiguous: SWD, SWO, `MCU_nRESET` and the
USART3 console are MCU pins and nothing else. Blocks J and K are board-level:

- **J, the rail probe header**, observes `+5V`, `+3V3` and `+3V3A`. Its strictly
  correct home under producer-owns-the-break (DEC-0007) is `power_rails`, which
  produces all three and already carries a test point, an isolation link and a
  current break per rail (`TEST_PLAN §3.3`, `TP301`/`TP305`). J duplicates none of
  that — it is a one-connector DMM convenience for bring-up steps 2 and 3, and step
  3 ("MCU alive: `+3V3` and `+3V3A` up") is an `mcu`-page gate. It went to `mcu`
  because `power_rails` was locked by a parallel review worker in the same wave and
  KiCad rewrites a whole sheet on every save, so two workers in one file is a
  guaranteed conflict (`AGENTS.md`). **Open for the captain:** move J to
  `power_rails`, or retire it as duplicate coverage. The block note on the sheet
  says so, so the question cannot be lost.
- **K, the GND hooks**, are scope-clip returns for hooks that live on six different
  sheets. They belong to no one block, and distributing six of them would have
  touched every sheet in the project mid-wave. One clearly-titled row on `mcu` is
  honest; their real placement is a layout decision and the note says so.

*What did not move.* Nothing was deleted and no net changed. The six debug nets —
`SWDIO`, `SWCLK`, `SWO`, `MCU_nRESET`, `DBG_TX`, `DBG_RX` — were shared only between
`mcu` and `test_debug`, so with the header on `mcu` they became **sheet-local
labels**: the hierarchical labels on both sides were converted to plain labels and
their twelve sheet pins came off the root.

### D-REV-02 — Page numbers renumber; reference-designator ranges do not

`test_debug` was page 4. The remaining nine blocks renumber 2..10 with no gap, so
the sheet count in the title block reads correctly. That breaks the old rule that a
sheet's designator range is its page number × 100 — `loadcell_afe` is now page 4 but
keeps 5xx.

Renumbering 60-odd components across seven sheets to restore the coincidence would
churn every sheet, every review note and the whole `TEST_PLAN`, for no gain. So the
allocation becomes a **fixed table** and **4xx is retired**. Written into `AGENTS.md`
and into the root sheet's own note.

### D-REV-03 — `docs/decisions/actuator-sch-mcu.md` is left as the historical record

That file is titled "`mcu` and `test_debug`". It is the design record of the wave
that drew them and stays accurate about *why* each circuit is what it is. It is not
rewritten here; this file supersedes it on where the circuits live.

---

## 2. R2 — the two clock domains are separated

### D-REV-04 — The USB3320 gets its own crystal; the STM32 keeps its own oscillator

This overturns the shared-reference half of `D-MCU-01` / OQ-03.

**USB3320 (new block C).** `Y1002 = ECS-240-12-23G-JGN-TR`, 24 MHz, 18 pF, −40 to
+85 °C, from `Amodo_Crystals.kicad_sym`, on the PHY's internal oscillator between
`REFCLK` (pin 26) and `XO` (pin 25) — USB3320 DS Figure 5-4. `XO`'s no-connect is
removed. `REFSEL[2:0] = 111` still selects a 24 MHz reference (DS Table 5-10), so no
configuration changes.

Load caps `C1025` / `C1026` = **27 pF C0G 2%** (`CAP_MLCC_27pF_0603_2%_50V_C0G`):
C = 2 × (C_L − C_stray) = 2 × (18 − 5) = 26 pF → 27 pF standard, with C_stray taken
as 3 pF pin capacitance (DS Table 4-11 gives 3 pF typ for both `REFCLK` and `XO`)
plus ~2 pF of PCB per side.

**Open for the captain / procurement:** DS Table 4-11 asks for ESR ≤ 30 Ω and
C_L 20 pF typ. 18 pF is fine for a parallel-resonant fundamental part inside the
±500 ppm budget, but **the ECS-23G ESR must be confirmed against 30 Ω before the
first order.** The block note on the sheet carries this.

**STM32 (block B).** `Y1001` keeps its ASEMB-24.000MHZ-LY-T MEMS oscillator and now
drives `PH0-OSC_IN` alone. `R1004`, the second 33 R of the old two-load fan-out, is
removed with its wiring; `R1003` still source-terminates the single trace. A bare
crystal on the STM32 is **not possible** without an `.ioc` change: `PH0-OSC_IN` is
set to *HSE-External-Clock-Source* and `PH1-OSC_OUT` is unallocated (`REQ-AR-16`),
and the `.ioc` is the pin authority (DEC-0013). Re-pinning it is a bigger decision
than a review fix, so the STM32 keeps a driven clock — which still gives the captain
what they asked for: **the two domains share nothing.**

### The netlist delta, in full

Everything else in the project netlist is byte-identical, node set for node set.

| Net | Before | After |
|---|---|---|
| `USB_REFCLK_24M` | `R1004.2`, `U1002.26` | `C1025.1`, `U1002.26`, `Y1002.1` |
| `USB_XO_24M` | — (`U1002.25` unconnected) | `C1026.1`, `U1002.25`, `Y1002.2` |
| `Net-(Y1001-OUT)` | `R1003.2`, `R1004.1`, `TP1003.1`, `Y1001.3` | `R1003.2`, `TP1003.1`, `Y1001.3` |
| `GND` | — | gains `C1025.2`, `C1026.2` |

Components: **−`R1004`**, **+`Y1002`, `C1025`, `C1026`**. Two auto-generated net
names follow the `J401 → J1003` rename (`Net-(J401-Pin_7)` → `Net-(J1003-Pin_7)`).

This branch's own contribution: 409 → 411 components, 253 nets unchanged. Rebased onto the
other two review branches the project stands at **398 components, 251 nets** — their power
rework accounts for the rest.

---

## 3. R3 / R4 — `mcu` on A2, flags in right-justified columns

### D-REV-05 — `mcu.kicad_sch` is A2; every other sheet stays A3

DEC-0020 said A3 throughout. A2 (594 × 420) is what makes R4 possible: a
right-justified flag column needs the longest name (`LINEAR_ENCODER_A`, ~18 mm) to
sit *outside* the wire, which does not fit to the left of a port unit on A3. Only
`mcu` grows; the other nine sheets are unchanged and A3 is still the default.
DEC-0020 is amended in `docs/DECISIONS.md` rather than replaced.

### D-REV-06 — Sheet entry / exit flags: `justify right`, text outside the wire

The port-unit flags were `(at x y 0) (justify left)`: the flag sits at the wire end
and the text runs **right, along the wire**, into the pin numbers — ragged right
edges, the exact thing the captain's screenshot showed. Changing them to
`(justify right)` flips the glyph and puts the text to the **left** of the anchor,
so all names right-align on the flag column and the wire runs clear to the pin.
Anchors did not move, so no wire changed and no net changed.

Net labels were left exactly as they are ("Net labels look good") — text over the
wire, left-justified. In a port column the two now read as: right-aligned flag names
outdented to the left, net-label names sitting on the wire.

### The A2 layout

| | |
|---|---|
| `A` MCU core · `B` STM32 24 MHz HSE oscillator · `D` OCTOSPI1 PSRAM · `F` USB3320C ULPI PHY · `G` USB-C · `E` USB PHY rails | unchanged positions, x ≤ 407.67 |
| `MCU PORTS` | one band, `U1001B/C/D` at 128.27 mm pitch, label columns at unit − 22.86 |
| `MCU PORTS (cont.)` | `U1001E/F`, same treatment |
| `SPARE MCU I/O BREAKOUT`, `SHEET NOTES` | moved, notes rewritten |
| `C` USB3320 24 MHz crystal · `H` debug header · `J` rail probe header | new right column, x 411.48..581.66 |
| `K` GND hooks | bottom band, six hooks in one row |

The five port-unit clusters, the spare-I/O breakout and the sheet notes moved as
whole clusters by a fixed translation, so their internal geometry is exactly what
was reviewed.

---

## 4. R5 / R6 — `ui_io`, graphical only

### D-REV-07 — Pre-rotated horizontal passives live in `faff2_passives.kicad_sym`

> **SUPERSEDED — the library and both symbols are gone.** The rotation rule is settled the other
> way: rotating a part on the schematic is normal, and needing an orientation is not a reason to
> make a library variant. `R907` and `R915` use the house symbols rotated 90°, with field angles
> compensated to 270 so their text still renders horizontal. `faff2_passives.kicad_sym` held
> nothing else and has been deleted along with its `sym-lib-table` entry. The record below is
> history.

`schematic-style` forbids instance rotation for orientation variants — it turns the
reference and value text sideways. The Amodo house library has no horizontal
resistor, so a project-local library was created:
`hardware/kicad/faff2_cbs1/faff2_passives.kicad_sym`, registered in `sym-lib-table`
through `${KIPRJMOD}`, holding `RES_TF_39R_0603_H` and `RES_TF_0R_0603_H` — the
Amodo symbols rotated +90° at source, with reference above and value below.

**For the captain:** these belong upstream in `Amodo_Resistors.kicad_sym` as house
horizontal variants; every project that draws an in-line series resistor needs them.
The library is read-only to us, so they are project-local for now.

### What changed on the sheet

- **SYNC / TRIGGER OUT.** The signal now runs one way, left to right, along
  y = 25.40: `U901A` pin 4 → `TP901` → `R907` (horizontal) → `TP902` → `D903` tee →
  `J902` SMA. `R907` used to drop the signal 10 mm down and back out again.
  `D903` shunts straight down off the line, body horizontal, ground below its anode.
- **END-OF-STROKE LIMITS.** `U902A` moved 20.32 mm right. `LIM_A` and `LIM_B` exit
  on clear stubs — the `+3V3` riser that ran through the `LIM_A` text is now at
  x = 152.40, and the two AND-gate input risers at 157.48 and 160.02, all well clear
  of both labels. `R915` is horizontal and in line: `U902A` pin 4 → `R915` →
  `R916` pull-up tee → `TP905` → `LIMIT_nBRK`, one direction throughout.
- One stale sheet note ("ERC reports `power_pin_not_driven` until that sheet lands")
  corrected — the project has been clean at severity-all since the root was wired.

**The `ui_io` netlist is identical, net for net and node for node.**

---

## 5. Verification

| Check | Result |
|---|---|
| `kicad-cli sch erc --severity-all --exit-code-violations`, nothing suppressed | **0 errors, 0 warnings**, exit 0 |
| Sheet load (stderr checked, netlist component count) | 398 components after rebase — no silent truncation |
| Netlist equivalence | every net's node set identical apart from the four rows in §2, after mapping the `test_debug → mcu` refdes renames |
| Designators | 0 unannotated, 0 out of range, 0 duplicates; `#PWR1001..1066` on `mcu` |
| Footprints | all 398 assigned; all 53 distinct footprints resolve to a library file |
| `schematic-style` overlap checker | `mcu` clean, `ui_io` clean, root clean. Every remaining finding is in a sheet this branch did not touch — the confirmed checker artefacts of `actuator-sch-integrate.md §7`, plus whatever the other two review branches left |
| Render sweep | all 10 pages |

The review PDF was **deliberately not regenerated** by this pass. Overtaken by
`DEC-0028`: no review PDF exists and none is to be generated.

## 6. Left for the captain

1. ~~**`J1004`, the rail probe header** — move to `power_rails`, or retire it as~~
   **Closed, review round 4: moved to `power_rails` as `J301`,** into block D,
   which already carries `RAIL_PGOOD`, `D303` and `TP308`. The rails, their
   isolation links and their current breaks are all on that sheet; the header
   only observes them. Original wording:
   duplicate coverage of `TP301`/`TP305`? (D-REV-01)
2. **`Y1002` ESR** — confirm the ECS-23G against the USB3320's ≤ 30 Ω before the
   first order. (D-REV-04)
3. ~~**`faff2_passives.kicad_sym`** — the two horizontal resistors want to be house
   parts in `Amodo_Resistors.kicad_sym`. (D-REV-07)~~ **Closed:** they are house parts,
   rotated on the schematic; the local library is deleted. Nothing is wanted upstream.
4. **DEC numbers** — D-REV-01..07 need real `DEC-00xx` numbers in
   `docs/DECISIONS.md`. They are not minted here because three review branches were
   in flight at once and would have raced for the same numbers. The one exception is
   DEC-0020, amended in place because "A3 sheets throughout" would otherwise be
   flatly wrong.

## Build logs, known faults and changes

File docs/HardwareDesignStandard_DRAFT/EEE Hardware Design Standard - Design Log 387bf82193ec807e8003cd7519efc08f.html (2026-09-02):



# EEE Hardware Design Standard - Design Log

# v0.0.1+

Engineer | @Toby Lane
Date | @June 22, 2026

<Fill design log content here, using heading 2 and heading 3 to structure>

## Working out what to write about:

Some content that likely wants covering:

Schematic:

- Involve FW from day 0
- Ideally start writing FW from early as possible
- If a board has a uC, probably shouldn’t order without a firmware at least reviewing the project so far (maybe this is optional as for very lean / lightweight projects, could be bad? QFOG example)
- Enforce the hardware logger for tracking bugs / mods on boards and their state
  - Maybe make this as a template of some kind?
- Test coverage

PCB:

- Something about how we very rarely design things with the intention of CE marking, or doing any kind of formal emissions / susceptibility around it, but how they are an extremely important thing to still consider when designing a piece of electronics
- Intermittent hardware problems and how time consuming they can be to solve
- Return currents and their related things:
  - Reference planes (or lack thereof)
  - Pitfall of the classic SIG:GND:PWR:SIG stackup
- Rise and fall times, and the pitfalls around moderns ICs
- ESD protection on interfaces
- Something RE switchmode power supply layout?
  - On this, something about decoupling capacitors and inductance and package sizes
- Something about design for test
  - TPs, preferably through hole
  - If a board needs to be small, and timelines allow, it is probably cheaper in the long run to make a big version first
  - Additional strapping Rs (PU vs PD)
  - Zero ohm links for measuring power consumption (although I never do this)

## Designing Something with a Microcontroller?

When designing a board with a microcontroller, you should always seek some guidance / review from a firmware engineer, ideally an engineer who has been involved in the decision making early on in the project. Even if it is just a 15 minute informal chat, you could save yourself a headache down the line when your boards turn up, and it turns out you don’t have a peripheral hooked up quite right. If you are unsure, ask one of the firmware Triage Points: Triage Points (https://app.notion.com/p/Triage-Points-343bf82193ec80ca9059da76d9bcddc9?pvs=21).

If you project has complex firmware requirements, like using a timing critical interface, or performing some tricky DSP, consider starting firmware development in parallel. The typical hardware development cycle has firmware starting when the first PCB is delivered. If firmware development can be started early using a development board, you are much more likely to encounter potential architecture / system design problems early.

## Test Coverage

The more test coverage you have on your PCB, the better. Good test coverage will substantially improve your experience whilst doing bringup, as well as make the engineer writing your firmware much happier! You are unlikely to ever regret placing that extra test point, but the chances are you will kick yourself if you don’t place it.

There are a few very useful parts in the AmodoKiCadLib that are worth knowing about:

- Standard TestPoint:
  - Typically configured for a 1.0 mm SMT pad.
  - Good for when space is tight, and you might want to quickly check a voltage / pin state with a DMM.
  - Bad for probing with an oscilloscope or logic analyser, as you will likely need to solder some wire on to it.
- TestPointHook:
  - A THT soldered loop that is fitted to a PTH on your PCB.
  - Good for when space is tight, and you know you are likely want to attach a scope probe or logic analyser to the net (e.g. I2C / SPI pins).
  - When placing these, make sure that you also put a few additional parts down tied to GND, so that you have something to attach your oscilloscope GND clip to.
- TestPointDual:
  - A THT test point designed for using an oscilloscope probe with a spring ground clip.
  - Good for when you know you will want to measure a net where signal integrity matters. There is a hole for the signal being measured, and a hole for where the scope probe GND spring goes to. In this case, the measurement loop area is very small, so you will minimise measurement inductance, reducing any false ringing, overshoot, and other probing artefacts. The small loop area also makes you less susceptible to magnetic field pickup from other circuits on your board.

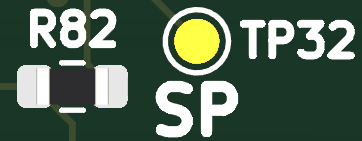
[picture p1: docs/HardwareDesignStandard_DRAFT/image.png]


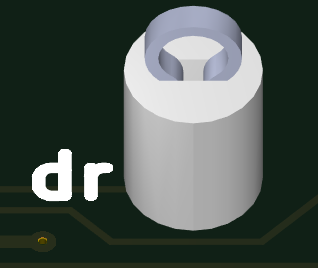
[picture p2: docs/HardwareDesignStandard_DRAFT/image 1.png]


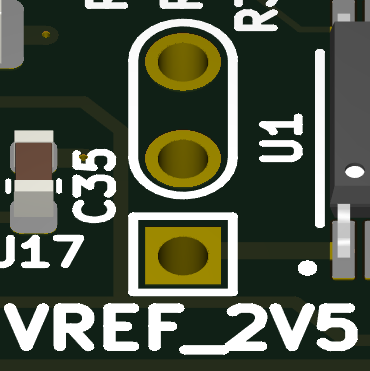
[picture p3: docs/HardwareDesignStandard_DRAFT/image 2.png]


If your PCB is very space constrained, and timelines allow, then you should consider making a ‘big’ first revision of the board. The ‘big’ board can have plenty of test coverage, and additional debug features that wouldn’t necessarily fit in the final mechanical package. This will significantly accelerate bringup, firmware development, and testing. Once you have proved the hardware, you can then miniaturise at a later date.

If your board has a net that you will likely want to spend a lot of time measuring with an oscilloscope, or injecting into with a signal generator, then use a coaxial connector of some kind. It is very convenient to be able to hook your test equipment up directly with an off the shelf cable. If space is tight, consider using a U.FL, and then probing with a U.FL to BNC adapter cable, which we stock in the EEE lab.

### A Quick Note on High Speed Signals

It is not advisable to place test coverage on very high speed interfaces or signals. The additional stub / stray capacitance added by a test point (particularly through hole), will introduce an impedance discontinuity that could lead to signal integrity problems. Additionally, conventional passive probes will likely distort or load the signal. Accurate probing may require a high-bandwidth, very-low-capacitance active probe, which we do not currently have. If you think you need to probe a digital signal with rise / fall times that are single digit nanosecond, or an analogue signal with bandwidth > 100 MHz, consider using a switched coaxial connector (https://www.murata.com/en-eu/products/connector/switchconnector).

## EMC, Why Should we Care?

At Amodo, we design lots of hardware. Almost none of the hardware that we design ends up being sold in any volume, and as such, we don’t often consider regulatory requirements.

If you want to sell an electronic device within the EU, you, the manufacturer, must affix the CE mark, and in doing so, you are declaring that your product is conformant to any relevant standards. For an electronic device, that typically means conforming with the Electromagnetic Compatibility (EMC) Directive.

We don’t usually sell our designs, and they are often produced one-off, or in the low tens of units, so why should we care about the EMC Directive?

The aim of the EMC Directive is to ensure that interconnected devices (whether that interconnect is intentional or not) don’t negatively impact the performance of one another. This not only covers emissions (noise generated by the product we designed), but also susceptibility (whether our product is affected by noise from an aggressor product). If we design a circuit board, and follow EMC good practices, we get the following:

- We reduce the chance that our product will negatively impact the performance of other products around it.
- We reduce the chance that our product will be negatively impacted by other products around it.
- In addition to these, we also reduce the chances of us encountering intra-system problems within our product. e.g. an IC’s reset pin being routed too close to a switchmode power supply, causing spurious reset.

EMC related problems are often difficult to predict, hard to reproduce, and complex to solve. As a result, they can consume huge amounts of engineering time. By applying the best practices defined within this document, we might spend a little more design time up front, but will gain this time back in the long run by reducing the number of hard to spot / reproduce / solve problems we unintentionally design in.

## Modern Silicon is FAST (and why clock speed doesn’t matter)!

At the output of a typical digital I/O pin, we typically find an NMOS and PMOS pair working in conjunction as a push-pull output (or simply just a pull-down NMOS in the open drain case). When we consider an edge, be that rising or falling, we are switching on one transistor whilst switching the other off. The rate at which these transition happen, known as the rise and fall times, is a function of the capacitance seen by the I/O pin, in combination with the drive strength (how quickly it can source / sink current to charge / discharge said capacitance).

Let’s take the example of an STM32H723 driving a 4 inch / 100 mm track, of 0.15 mm width (on the EuroCircuits standard proto-pool for 4 layers). This track will have a load capacitance of around 6 pF. If we take a look at the H723 datasheet, for an I/O pin in very high speed mode, powered from 3.3 V, and driving a 10 pF load, we should expect the rise and fall time to be on the order of 1.5 ns. We can therefore estimate the bandwidth of this edge at around 230 MHz (BW ~= 0.35 / Tr). A 100 mm track on FR4 routed as microstrip will be an effective 1/4 wavelength antenna at around 4-500 MHz or so. Our signal likely has some meaningful energy at this frequency. If our signal is routed over a clean GND plane, then it is quite likely that our track will act as a very poor antenna, and we likely have nothing to worry about. However, if we are using a fairly typical layer stackup; SIG,GND,PWR,SIG, then we might run into problems!

## Current Flow, the Path of Least Impedance

To state a few obvious things:

- Current flows in loops.
- DC current finds the path of least resistance.
- AC current finds the path of least impedance.

If we consider the AC current case, at high frequencies, the path of least impedance turns out to be the path of least inductance, because the impedance of an inductor rises with frequency. If we re-introduce the previous example of an I/O pin driving a trace, that signal will have some outgoing current, that flows into the load, and a return current, that flows from the load back to the source. On a schematic, that return current that flows back to the source is typically shown as flowing into your schematics ideal GND net. On the PCB, this will not be the case. The high frequency portion of this current will return via the path of least inductance, which is proportional to the area of the loop, and thus, the path taken will be that with the least loop area. Typically what this means, for a multi-layer PCB, is that the return current flows in the copper on the nearest neighbouring layer.

Continuing the last example, let’s say that we are designing a PCB with components on the top layer, signals on the top and bottom layers, a continuous GND / 0 V plane on inner layer 1, and power planes on inner layer 2. Let’s say that the power plane is made up of a mixture of 12 V, 5 V, and 3.3 V polygons to distribute power across the board. If we consider a digital signal travelling on the bottom layer, the return current will be on inner layer 2. Every time we cross a split between power polygons, we introduce a discontinuity / gap that the return current must find it’s way across. Without an EM field solver, we can’t predict what this path is going to be, and so we can’t predict the loop area. If the loop area is large, the inductance is high. High loop inductance means:

- There will be more voltage noise (), which will appear as ground bounce (a difference in GND potential across the board).
- We will be more susceptible to noise produced by other circuitry because a larger loop area effectively acts as a better pickup antenna.

A slightly more intuitive way to think about this is the fields based approach (imagine the field being a river, and the copper being the riverbank that guides the flow of water (fields)). Imagine our microstrip trace travelling over a clean GND / reference plane:

- We will develop an electric field between our outgoing signal trace, and the reference plane. The field lines will be well defined because the spacing between signal trace and reference plane is small and uniform.
- We will develop a magnetic field surrounding our signal trace. We will also develop a magnetic field surrounding our return current path. Because we routed over a clean reference plane, our loop area is small, so these fields are well contained.

If instead, we route our track over a split in the return plane, the return current must detour, increasing the loop area, and causing the fields to spread into a larger volume. A key thing to remember is that high-frequency return currents do not simply follow the copper labelled “GND”. They follow the path of lowest impedance, which is almost always the closest continuous reference conductor. If that reference conductor has splits, gaps, or discontinuities, the return path is disturbed, and the resulting larger area current loop can create more noise.

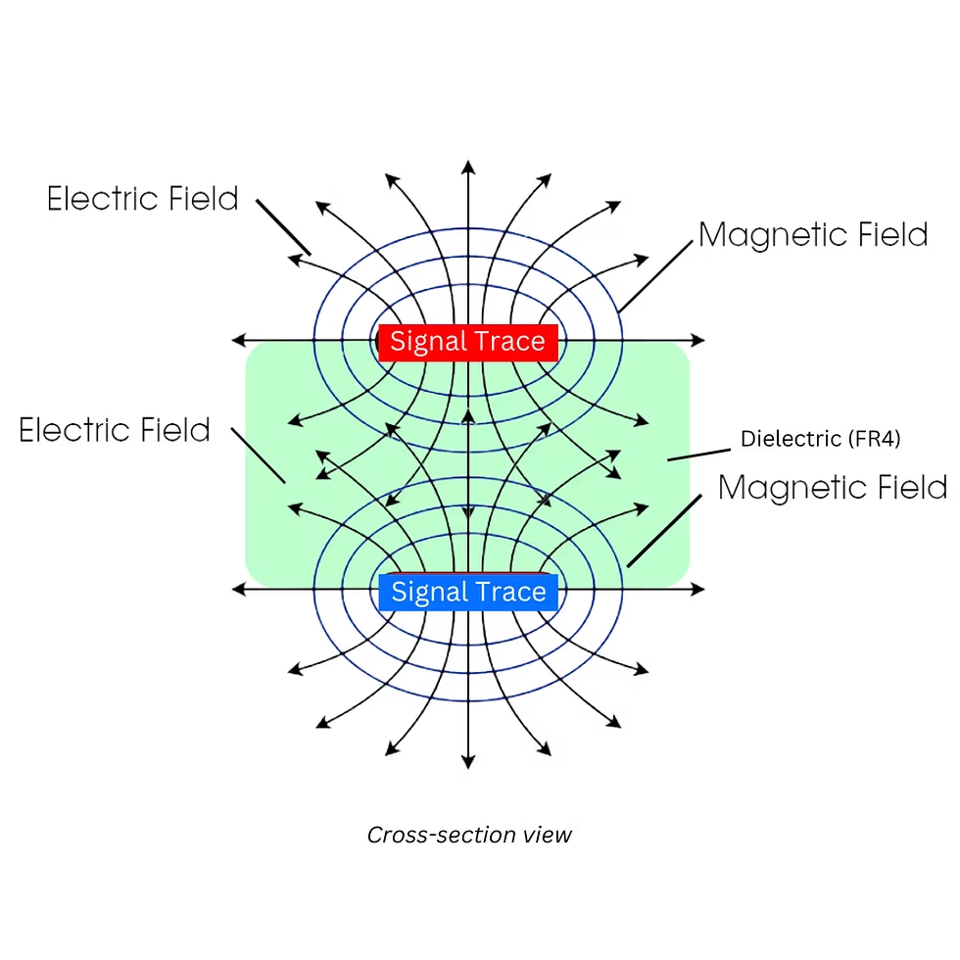
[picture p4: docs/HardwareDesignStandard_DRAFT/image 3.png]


WRITE A SECTION (MAYBE HERE) ON RETURN PATH VIAS FOR LAYER CHANGES

## So How Should We Plan the Stackup For a Four-Layer PCB?

Rather than using the typical SIG:GND:PWR:SIG, I would instead suggest using SIG+PWR:GND:GND:SIG+PWR.

Route power using 0.5 mm traces. A 100 mm long power trace (0.5 mm width) can carry a load current of 1 A, with just 125 mV of drop. If you are happy to accept a 20 degree temperature rise in the track, you can deliver over 2.5 A. You only need to consider using power planes if you need to deliver tens of amps to a load, or your downstream circuit is intolerant to voltage drop along the power supply conductor.

If you don’t have space or time to route power, then consider going for a 6-layer stackup, and using the inner-most layers to distribute power (SIG:GND:PWR/GND:PWR/GND:GND:SIG). For a standard 100x100 mm EuroCircuits board, going from 4 layers to 6 layers (at 5-off) is a per-board cost increase from £42 to £70 (and an additional 4 days lead time). You’ll probably save that additional cost in reduced layout time. If you save yourself from running into a signal integrity problem, you will have saved significant engineering time and project budget.

### What If I Need to Break the Rules?

If you are going to route a track with fast rise and fall times (with respect to trace length) over a separation between two power polygons on the next layer below, then you must place a capacitor over the split, with a via connecting them together. This will provide a low impedance path for the return currents.

If you are going to use a power plane as reference for a signal (e.g. when using SIG:GND:PWR:SIG), and that signal needs to change layer (e.g. from bottom to top), then the return currents also need to change layer. Usually, we would place a return path via, but we can’t directly add a via between GND and your PWR net, as this will be a short. In this case, you must place a decoupling capacitor that allows high frequency return currents to transition from the PWR net to the GND net. It must be placed very close to the signal via.

## Keeping Track of Hardware

So you’ve received the first revision of your board, and you’ve done lots of testing. Chances are, you’ll have found a few tweaks / modifications that need making. This might be a resistor value change, or perhaps a simple wire mod. Chances are, you have a few copies of your first board revision, and so might need to make mods on multiple boards. You might end up changing different things across the boards, to experiment with different possible solutions.

At this stage it is absolutely imperative that you make some documentation that describes what hardware has been built, what testing has been done on it, and what modification state all boards are in. Any engineer at Amodo should be able to pick up a PCB, read the serial number, find the relevant documentation, and understand what state the hardware is in, as well as how it might differ from the original data that was manufactured.

A great way to do this is using a Notion Database.

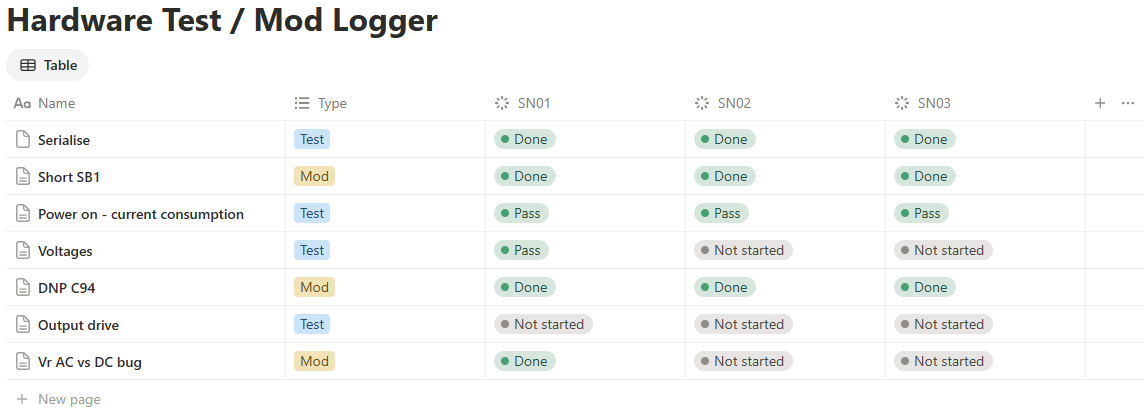
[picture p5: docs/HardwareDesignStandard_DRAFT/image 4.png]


Each test or modification is a new entry to the database. There is a column that defines the type, and a column for each physical piece of hardware you have. The status’s can be updated as and when boards are modified. Details on the test or modification carried out can be written in the page for each database entry. An example for a modification:

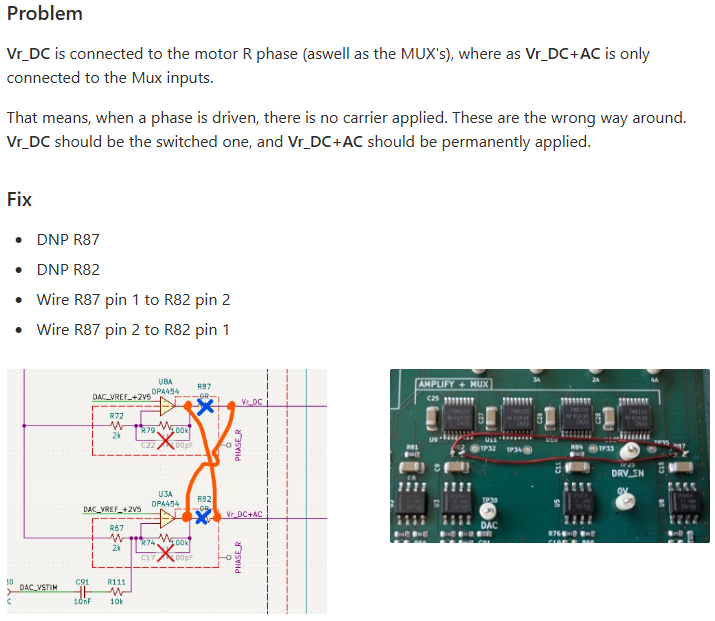
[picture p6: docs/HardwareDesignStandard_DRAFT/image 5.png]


You can view the example here:

 ARIA_SANGT_ELEC_PH1_CBs_1 - Bringup and Test - v0.1 (https://app.notion.com/p/ARIA_SANGT_ELEC_PH1_CBs_1-Bringup-and-Test-v0-1-33cbf82193ec803ab71bd1e1664ee8ff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)

Found this, and I am glad that I did:

https://resources.altium.com/p/dan-beeker-its-all-about-the-space

Final PDF Snapshot:

1. Modify title to reflect versions this document covers in the format ‘Design Log vX.Y.Z to vA.B.C’ inclusive of versions.
2. Press ‘…’ → Export to get PDF.
3. Type ‘/file’ and upload to leave snapshot.
4. Change document type from ‘Live Document’ to ‘Release’.
5. Delete this list!



Use buttons to add new version blocks!

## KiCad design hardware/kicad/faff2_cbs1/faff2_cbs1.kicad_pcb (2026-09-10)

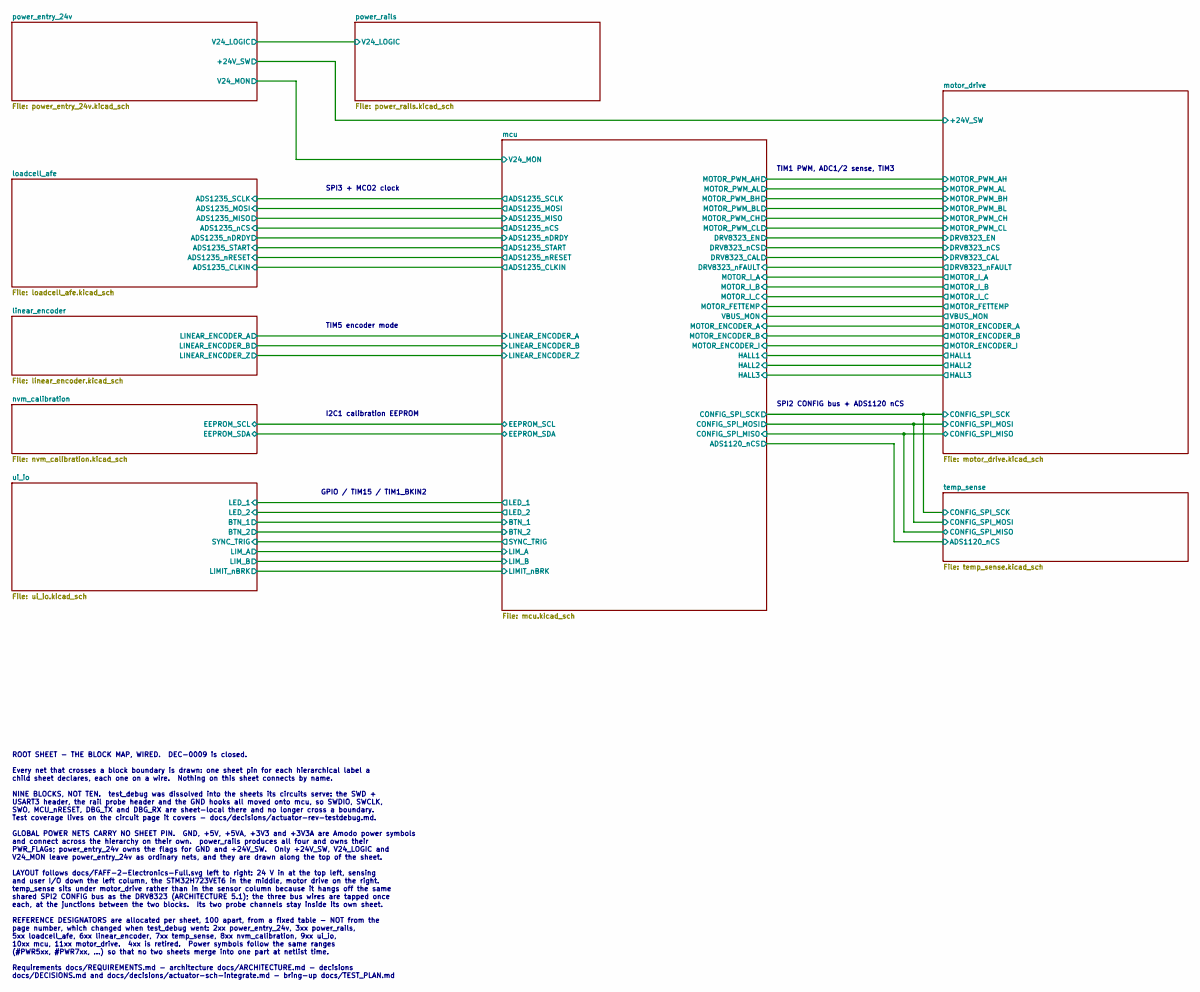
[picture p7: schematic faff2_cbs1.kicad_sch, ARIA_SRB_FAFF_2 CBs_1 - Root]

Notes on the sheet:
ROOT SHEET - THE BLOCK MAP, WIRED. DEC-0009 is closed. Every net that crosses a block boundary is drawn: one sheet pin for each hierarchical label a child sheet declares, each one on a wire. Nothing on this sheet connects by name. NINE BLOCKS, NOT TEN. test_debug was dissolved into the sheets its c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
GPIO / TIM15 / TIM1_BKIN2
SPI3 + MCO2 clock
TIM5 encoder mode
SPI2 CONFIG bus + ADS1120 nCS
TIM1 PWM, ADC1/2 sense, TIM3
I2C1 calibration EEPROM

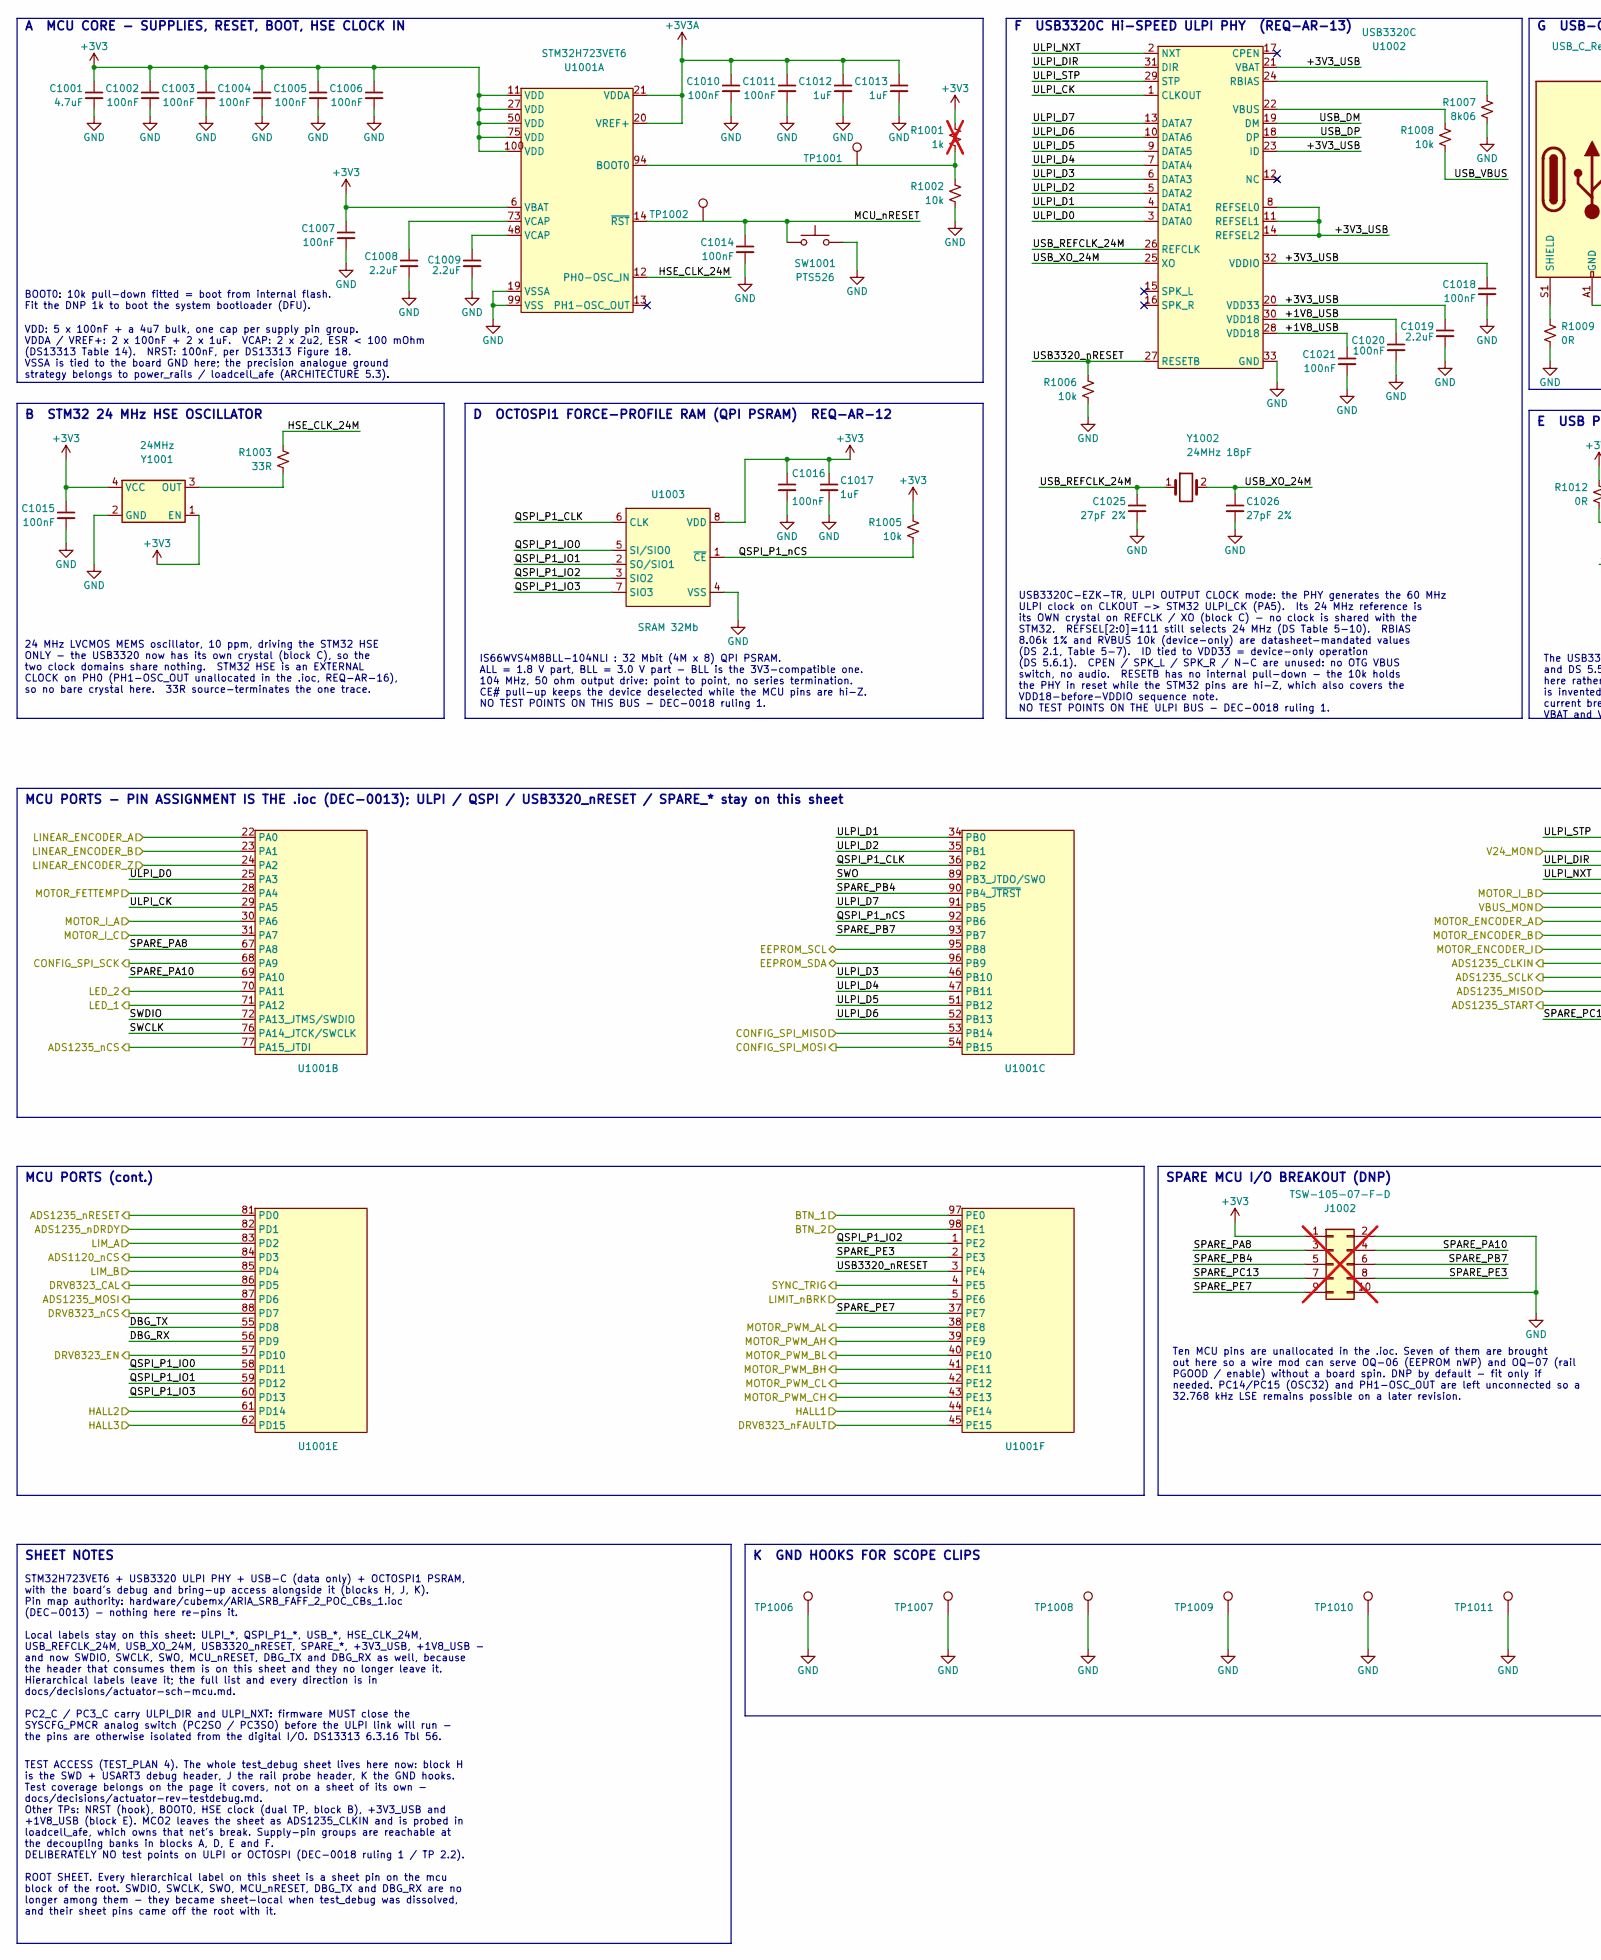
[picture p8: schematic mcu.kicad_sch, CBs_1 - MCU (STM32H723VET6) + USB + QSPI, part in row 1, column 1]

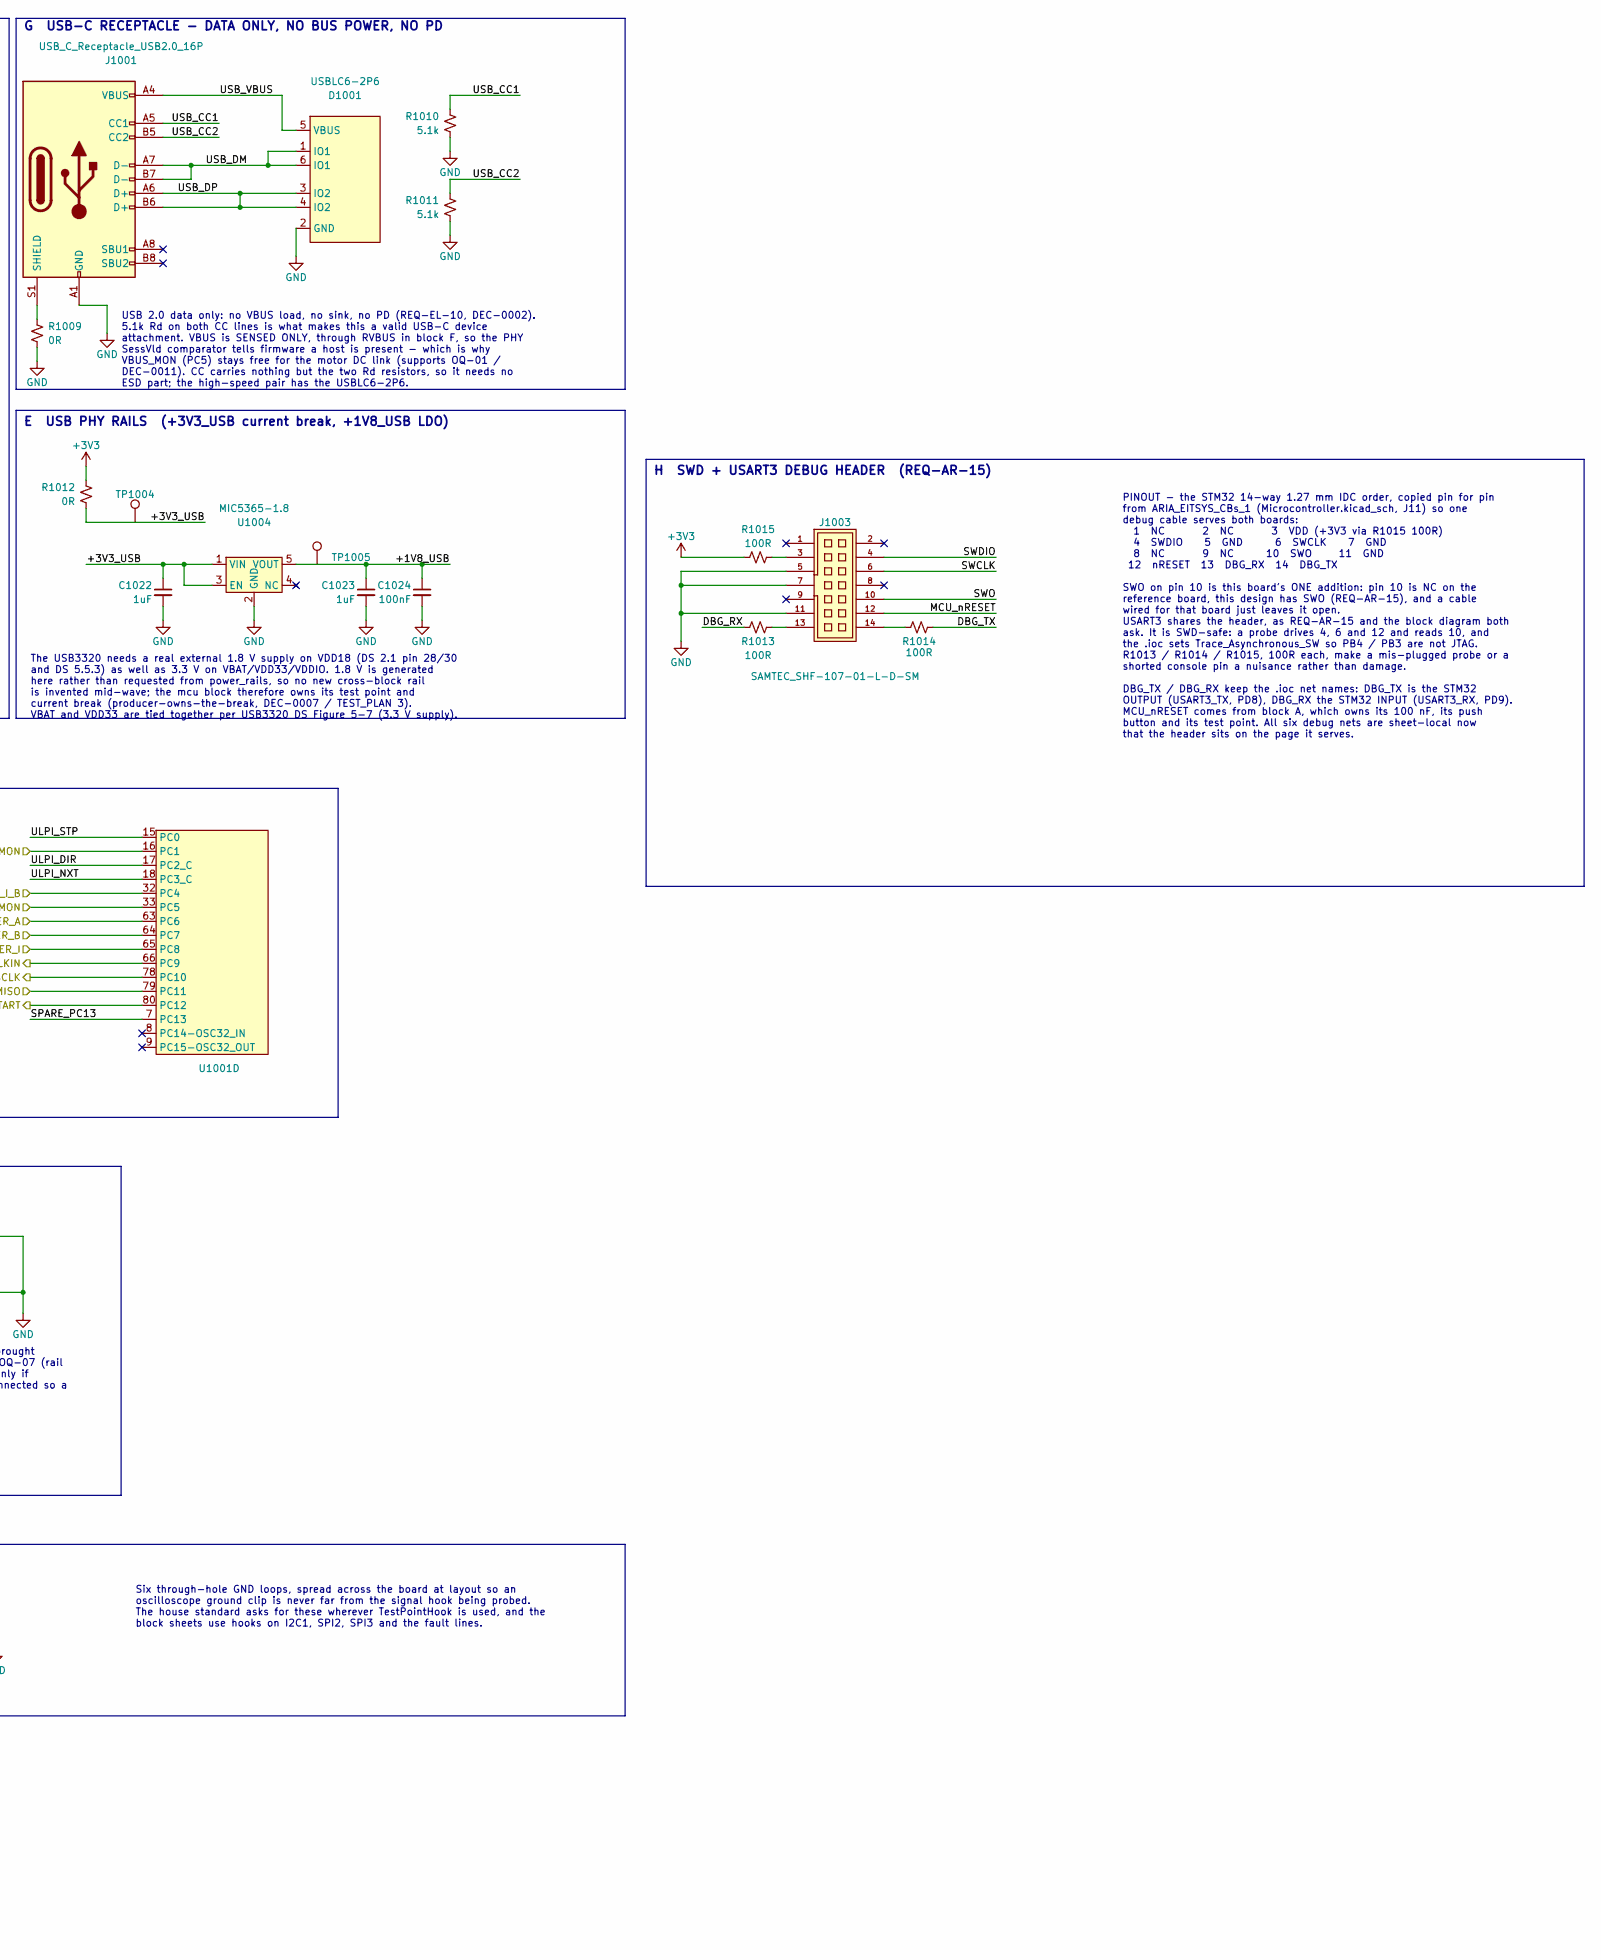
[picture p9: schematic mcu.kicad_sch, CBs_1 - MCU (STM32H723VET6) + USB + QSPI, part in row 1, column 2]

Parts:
C1001: 4.7uF; C_0603_1608Metric; mpn ZRB18AR6YA475ME05L
C1002, C1003, C1004, C1005, C1006, C1007, C1010, C1011, C1014, C1015, C1016, C1018, C1020, C1021, C1024: 100nF; C_0402_1005Metric; mpn 04025C104KAT2A
C1008, C1009, C1019: 2.2uF; C_0603_1608Metric; mpn GRM188Z71C225KE43J
C1012, C1013, C1017, C1022, C1023: 1uF; C_0402_1005Metric; mpn KGM05AR51E105KH
C1025, C1026: 27pF 2%; C_0603_1608Metric; mpn 06035A270GAT2A
D1001: USBLC6-2P6; SOT666 - ST; mpn USBLC6-2P6
J1001: USB_C_Receptacle_USB2.0_16P; USB_C_Receptacle_GCT_USB4110; mpn USB4110-GF-A
J1002: TSW-105-07-F-D; mpn TSW-105-07-F-D; not fitted
J1003: SAMTEC_SHF-107-01-L-D-SM; mpn SHF-107-01-L-D-SM
R1001: 1k; R_0603_1608Metric; mpn CR0603AFX-1001ELF; not fitted
R1002, R1005, R1006, R1008: 10k; R_0603_1608Metric; mpn ERJ-3EKF1002V
R1003: 33R; R_0603_1608Metric; mpn ERJ-3EKF33R0V
R1007: 8k06; R_0603_1608Metric; mpn CRCW06038K06FKEA
R1009, R1012: 0R; R_0603_1608Metric; mpn RC0603FR-070RL
R1010, R1011: 5.1k; R_0603_1608Metric; mpn CRCW06035K10FKEBC
R1013, R1014, R1015: 100R; R_0603_1608Metric; mpn ERJ-3EKF1000V
SW1001: PTS526; PTS526_1.5mm_G; mpn PTS526 SK15 SMTR2 LFS
TP1001: BOOT0; TestPoint_Pad_D1.0mm
TP1002: nRST; KeystoneMiniatureTestLoop; mpn 5002
TP1004: 3V3U; TestPoint_Pad_D1.0mm
TP1005: 1V8U; TestPoint_Pad_D1.0mm
TP1006, TP1007, TP1008, TP1009, TP1010, TP1011: GND; KeystoneMiniatureTestLoop; mpn 5002
U1001: STM32H723VET6; LQFP100; mpn STM32H723VET6
U1002: USB3320C; QFN-32 - 5x5mm - P0.5mm - EP3.3x3.3mm; mpn USB3320C-EZK-TR
U1003: SRAM 32Mb; SOIC-8 5x4; mpn IS66WVS4M8BLL-104NLI
U1004: MIC5365-1.8; SC-70-5; mpn MIC5365-1.8YC5-TR
Y1001: 24MHz; OSC_3.2MMX2.5MM; mpn ASEMB-24.000MHZ-LY-T
Y1002: 24MHz 18pF; Crystal_SMD_0603_2Pin_6.0x3.5mm; mpn ECS-240-12-23G-JGN-TR

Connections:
+3V3: C1001.1, C1002.1, C1003.1, C1004.1, C1005.1, C1006.1, C1007.1, C1015.1, C1016.1, C1017.1, J1002.1, R1001.1, R1005.1, R1012.1, R1015.1, U1001.6 (VBAT), U1001.11 (VDD), U1001.27 (VDD), U1001.50 (VDD), U1001.75 (VDD), U1001.100 (VDD), U1003.8 (VDD), Y1001.1 (EN), Y1001.4 (VCC); also elsewhere on the board
+3V3A: C1010.1, C1011.1, C1012.1, C1013.1, U1001.20 (VREF+), U1001.21 (VDDA); also elsewhere on the board
/linear_encoder/LINEAR_ENCODER_A: U1001.22 (PA0); also elsewhere on the board
/linear_encoder/LINEAR_ENCODER_B: U1001.23 (PA1); also elsewhere on the board
/linear_encoder/LINEAR_ENCODER_Z: U1001.24 (PA2); also elsewhere on the board
/loadcell_afe/ADS1235_CLKIN: U1001.66 (PC9); also elsewhere on the board
/loadcell_afe/ADS1235_MISO: U1001.79 (PC11); also elsewhere on the board
/loadcell_afe/ADS1235_MOSI: U1001.87 (PD6); also elsewhere on the board
/loadcell_afe/ADS1235_SCLK: U1001.78 (PC10); also elsewhere on the board
/loadcell_afe/ADS1235_START: U1001.80 (PC12); also elsewhere on the board
/loadcell_afe/ADS1235_nCS: U1001.77 (PA15_JTDI); also elsewhere on the board
/loadcell_afe/ADS1235_nDRDY: U1001.82 (PD1); also elsewhere on the board
/loadcell_afe/ADS1235_nRESET: U1001.81 (PD0); also elsewhere on the board
/mcu/+1V8_USB: C1020.1, C1021.1, C1023.1, C1024.1, TP1005.1, U1002.28 (VDD18), U1002.30 (VDD18), U1004.5 (VOUT)
/mcu/+3V3_USB: C1018.1, C1019.1, C1022.1, R1012.2, TP1004.1, U1002.8 (REFSEL0), U1002.11 (REFSEL1), U1002.14 (REFSEL2), U1002.20 (VDD33), U1002.21 (VBAT), U1002.23 (ID), U1002.32 (VDDIO), U1004.1 (VIN), U1004.3 (EN)
/mcu/BTN_1: U1001.97 (PE0); also elsewhere on the board
/mcu/BTN_2: U1001.98 (PE1); also elsewhere on the board
/mcu/DBG_RX: R1013.1, U1001.56 (PD9)
/mcu/DBG_TX: R1014.2, U1001.55 (PD8)
/mcu/DRV8323_CAL: U1001.86 (PD5); also elsewhere on the board
/mcu/DRV8323_EN: U1001.57 (PD10); also elsewhere on the board
/mcu/DRV8323_nCS: U1001.88 (PD7); also elsewhere on the board
/mcu/DRV8323_nFAULT: U1001.45 (PE15); also elsewhere on the board
/mcu/EEPROM_SCL: U1001.95 (PB8); also elsewhere on the board
/mcu/EEPROM_SDA: U1001.96 (PB9); also elsewhere on the board
/mcu/HALL1: U1001.44 (PE14); also elsewhere on the board
/mcu/HALL2: U1001.61 (PD14); also elsewhere on the board
/mcu/HALL3: U1001.62 (PD15); also elsewhere on the board
/mcu/HSE_CLK_24M: R1003.1, U1001.12 (PH0-OSC_IN)
/mcu/LED_1: U1001.71 (PA12); also elsewhere on the board
/mcu/LED_2: U1001.70 (PA11); also elsewhere on the board
/mcu/LIMIT_nBRK: U1001.5 (PE6); also elsewhere on the board
/mcu/LIM_A: U1001.83 (PD2); also elsewhere on the board
/mcu/LIM_B: U1001.85 (PD4); also elsewhere on the board
/mcu/MCU_nRESET: C1014.1, J1003.12, SW1001.1_2, TP1002.1, U1001.14 (~RST)
/mcu/MOTOR_ENCODER_A: U1001.63 (PC6); also elsewhere on the board
/mcu/MOTOR_ENCODER_B: U1001.64 (PC7); also elsewhere on the board
/mcu/MOTOR_ENCODER_I: U1001.65 (PC8); also elsewhere on the board
/mcu/MOTOR_FETTEMP: U1001.28 (PA4); also elsewhere on the board
/mcu/MOTOR_I_A: U1001.30 (PA6); also elsewhere on the board
/mcu/MOTOR_I_B: U1001.32 (PC4); also elsewhere on the board
/mcu/MOTOR_I_C: U1001.31 (PA7); also elsewhere on the board
/mcu/MOTOR_PWM_AH: U1001.39 (PE9); also elsewhere on the board
/mcu/MOTOR_PWM_AL: U1001.38 (PE8); also elsewhere on the board
/mcu/MOTOR_PWM_BH: U1001.41 (PE11); also elsewhere on the board
/mcu/MOTOR_PWM_BL: U1001.40 (PE10); also elsewhere on the board
/mcu/MOTOR_PWM_CH: U1001.43 (PE13); also elsewhere on the board
/mcu/MOTOR_PWM_CL: U1001.42 (PE12); also elsewhere on the board
/mcu/QSPI_P1_CLK: U1001.36 (PB2), U1003.6 (CLK)
/mcu/QSPI_P1_IO0: U1001.58 (PD11), U1003.5 (SI/SIO0)
/mcu/QSPI_P1_IO1: U1001.59 (PD12), U1003.2 (SO/SIO1)
/mcu/QSPI_P1_IO2: U1001.1 (PE2), U1003.3 (SIO2)
/mcu/QSPI_P1_IO3: U1001.60 (PD13), U1003.7 (SIO3)
/mcu/QSPI_P1_nCS: R1005.2, U1001.92 (PB6), U1003.1 (~CE)
/mcu/SPARE_PA8: J1002.3, U1001.67 (PA8)
/mcu/SPARE_PA10: J1002.4, U1001.69 (PA10)
/mcu/SPARE_PB4: J1002.5, U1001.90 (PB4_~JTRST)
/mcu/SPARE_PB7: J1002.6, U1001.93 (PB7)
/mcu/SPARE_PC13: J1002.7, U1001.7 (PC13)
/mcu/SPARE_PE3: J1002.8, U1001.2 (PE3)
/mcu/SPARE_PE7: J1002.9, U1001.37 (PE7)
/mcu/SWCLK: J1003.6, U1001.76 (PA14_JTCK/SWCLK)
/mcu/SWDIO: J1003.4, U1001.72 (PA13_JTMS/SWDIO)
/mcu/SWO: J1003.10, U1001.89 (PB3_JTDO/SWO)
/mcu/SYNC_TRIG: U1001.4 (PE5); also elsewhere on the board
/mcu/ULPI_CK: U1001.29 (PA5), U1002.1 (CLKOUT)
/mcu/ULPI_D0: U1001.25 (PA3), U1002.3 (DATA0)
/mcu/ULPI_D1: U1001.34 (PB0), U1002.4 (DATA1)
/mcu/ULPI_D2: U1001.35 (PB1), U1002.5 (DATA2)
/mcu/ULPI_D3: U1001.46 (PB10), U1002.6 (DATA3)
/mcu/ULPI_D4: U1001.47 (PB11), U1002.7 (DATA4)
/mcu/ULPI_D5: U1001.51 (PB12), U1002.9 (DATA5)
/mcu/ULPI_D6: U1001.52 (PB13), U1002.10 (DATA6)
/mcu/ULPI_D7: U1001.91 (PB5), U1002.13 (DATA7)
/mcu/ULPI_DIR: U1001.17 (PC2_C), U1002.31 (DIR)
/mcu/ULPI_NXT: U1001.18 (PC3_C), U1002.2 (NXT)
/mcu/ULPI_STP: U1001.15 (PC0), U1002.29 (STP)
/mcu/USB3320_nRESET: R1006.1, U1001.3 (PE4), U1002.27 (RESETB)
/mcu/USB_CC1: J1001.A5 (CC1), R1010.1
/mcu/USB_CC2: J1001.B5 (CC2), R1011.1
/mcu/USB_DM: D1001.1 (IO1), D1001.6 (IO1), J1001.A7 (D-), J1001.B7 (D-), U1002.19 (DM)
/mcu/USB_DP: D1001.3 (IO2), D1001.4 (IO2), J1001.A6 (D+), J1001.B6 (D+), U1002.18 (DP)
/mcu/USB_REFCLK_24M: C1025.1, U1002.26 (REFCLK), Y1002.1
/mcu/USB_VBUS: D1001.5 (VBUS), J1001.A4 (VBUS), J1001.A9 (VBUS), J1001.B4 (VBUS), J1001.B9 (VBUS), R1008.2
/mcu/USB_XO_24M: C1026.1, U1002.25 (XO), Y1002.2
/mcu/V24_MON: U1001.16 (PC1); also elsewhere on the board
/mcu/VBUS_MON: U1001.33 (PC5); also elsewhere on the board
/temp_sense/ADS1120_nCS: U1001.84 (PD3); also elsewhere on the board
/temp_sense/CONFIG_SPI_MISO: U1001.53 (PB14); also elsewhere on the board
/temp_sense/CONFIG_SPI_MOSI: U1001.54 (PB15); also elsewhere on the board
/temp_sense/CONFIG_SPI_SCK: U1001.68 (PA9); also elsewhere on the board
GND: C1001.2, C1002.2, C1003.2, C1004.2, C1005.2, C1006.2, C1007.2, C1008.2, C1009.2, C1010.2, C1011.2, C1012.2, C1013.2, C1014.2, C1015.2, C1016.2, C1017.2, C1018.2, C1019.2, C1020.2, C1021.2, C1022.2, C1023.2, C1024.2, C1025.2, C1026.2, D1001.2 (GND), J1001.A1 (GND), J1001.A12 (GND), J1001.B1 (GND), J1001.B12 (GND), J1002.2, J1002.10, J1003.5, J1003.7, J1003.11, R1002.2, R1006.2, R1007.2, R1009.2, R1010.2, R1011.2, SW1001.3_4, TP1006.1, TP1007.1, TP1008.1, TP1009.1, TP1010.1, TP1011.1, U1001.10 (VSS), U1001.19 (VSSA), U1001.26 (VSS), U1001.49 (VSS), U1001.74 (VSS), U1001.99 (VSS), U1002.33 (GND), U1003.4 (VSS), U1004.2 (GND), Y1001.2 (GND); also elsewhere on the board
unnamed: C1008.1, U1001.73 (VCAP)
unnamed: C1009.1, U1001.48 (VCAP)
unnamed: J1001.S1 (SHIELD), R1009.1
unnamed: J1003.3, R1015.2
unnamed: J1003.13, R1013.2
unnamed: J1003.14, R1014.1
unnamed: R1001.2, R1002.1, TP1001.1, U1001.94 (BOOT0)
unnamed: R1007.1, U1002.24 (RBIAS)
unnamed: R1008.1, U1002.22 (VBUS)
unnamed: R1003.2, Y1001.3 (OUT)

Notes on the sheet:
BOOT0: 10k pull-down fitted = boot from internal flash. Fit the DNP 1k to boot the system bootloader (DFU).
MCU PORTS (cont.)
SPARE MCU I/O BREAKOUT (DNP)
IS66WVS4M8BLL-104NLI : 32 Mbit (4M x 8) QPI PSRAM. ALL = 1.8 V part, BLL = 3.0 V part - BLL is the 3V3-compatible one. 104 MHz, 50 ohm output drive: point to point, no series termination. CE# pull-up keeps the device deselected while the MCU pins are hi-Z. NO TEST POINTS ON THIS BUS - DEC-0018 ruli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
A MCU CORE - SUPPLIES, RESET, BOOT, HSE CLOCK IN
USB3320C-EZK-TR, ULPI OUTPUT CLOCK mode: the PHY generates the 60 MHz ULPI clock on CLKOUT -> STM32 ULPI_CK (PA5). Its 24 MHz reference is its OWN crystal on REFCLK / XO (block C) - no clock is shared with the STM32. REFSEL[2:0]=111 still selects 24 MHz (DS Table 5-10). RBIAS 8.06k 1% and RVBUS 10k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
F USB3320C Hi-SPEED ULPI PHY (REQ-AR-13)
D OCTOSPI1 FORCE-PROFILE RAM (QPI PSRAM) REQ-AR-12
The USB3320 needs a real external 1.8 V supply on VDD18 (DS 2.1 pin 28/30 and DS 5.5.3) as well as 3.3 V on VBAT/VDD33/VDDIO. 1.8 V is generated here rather than requested from power_rails, so no new cross-block rail is invented mid-wave; the mcu block therefore owns its test point and current brea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
SHEET NOTES
B STM32 24 MHz HSE OSCILLATOR
K GND HOOKS FOR SCOPE CLIPS
E USB PHY RAILS (+3V3_USB current break, +1V8_USB LDO)
Six through-hole GND loops, spread across the board at layout so an oscilloscope ground clip is never far from the signal hook being probed. The house standard asks for these wherever TestPointHook is used, and the block sheets use hooks on I2C1, SPI2, SPI3 and the fault lines.
PINOUT - the STM32 14-way 1.27 mm IDC order, copied pin for pin from ARIA_EITSYS_CBs_1 (Microcontroller.kicad_sch, J11) so one debug cable serves both boards: 1 NC 2 NC 3 VDD (+3V3 via R1015 100R) 4 SWDIO 5 GND 6 SWCLK 7 GND 8 NC 9 NC 10 SWO 11 GND 12 nRESET 13 DBG_RX 14 DBG_TX SWO on pin 10 is thi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
H SWD + USART3 DEBUG HEADER (REQ-AR-15)
TEST ACCESS (TEST_PLAN 4). The whole test_debug sheet lives here now: block H is the SWD + USART3 debug header, J the rail probe header, K the GND hooks. Test coverage belongs on the page it covers, not on a sheet of its own - docs/decisions/actuator-rev-testdebug.md. Other TPs: NRST (hook), BOOT0,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
STM32H723VET6 + USB3320 ULPI PHY + USB-C (data only) + OCTOSPI1 PSRAM, with the board's debug and bring-up access alongside it (blocks H, J, K). Pin map authority: hardware/cubemx/ARIA_SRB_FAFF_2_POC_CBs_1.ioc (DEC-0013) - nothing here re-pins it. Local labels stay on this sheet: ULPI_*, QSPI_P1_*,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
VDD: 5 x 100nF + a 4u7 bulk, one cap per supply pin group. VDDA / VREF+: 2 x 100nF + 2 x 1uF. VCAP: 2 x 2u2, ESR < 100 mOhm (DS13313 Table 14). NRST: 100nF, per DS13313 Figure 18. VSSA is tied to the board GND here; the precision analogue ground strategy belongs to power_rails / loadcell_afe (ARCHI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
USB 2.0 data only: no VBUS load, no sink, no PD (REQ-EL-10, DEC-0002). 5.1k Rd on both CC lines is what makes this a valid USB-C device attachment. VBUS is SENSED ONLY, through RVBUS in block F, so the PHY SessVld comparator tells firmware a host is present - which is why VBUS_MON (PC5) stays free 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
G USB-C RECEPTACLE - DATA ONLY, NO BUS POWER, NO PD
24 MHz LVCMOS MEMS oscillator, 10 ppm, driving the STM32 HSE ONLY - the USB3320 now has its own crystal (block C), so the two clock domains share nothing. STM32 HSE is an EXTERNAL CLOCK on PH0 (PH1-OSC_OUT unallocated in the .ioc, REQ-AR-16), so no bare crystal here. 33R source-terminates the one t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
Ten MCU pins are unallocated in the .ioc. Seven of them are brought out here so a wire mod can serve OQ-06 (EEPROM nWP) and OQ-07 (rail PGOOD / enable) without a board spin. DNP by default - fit only if needed. PC14/PC15 (OSC32) and PH1-OSC_OUT are left unconnected so a 32.768 kHz LSE remains possi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
MCU PORTS - PIN ASSIGNMENT IS THE .ioc (DEC-0013); ULPI / QSPI / USB3320_nRESET / SPARE_* stay on this sheet

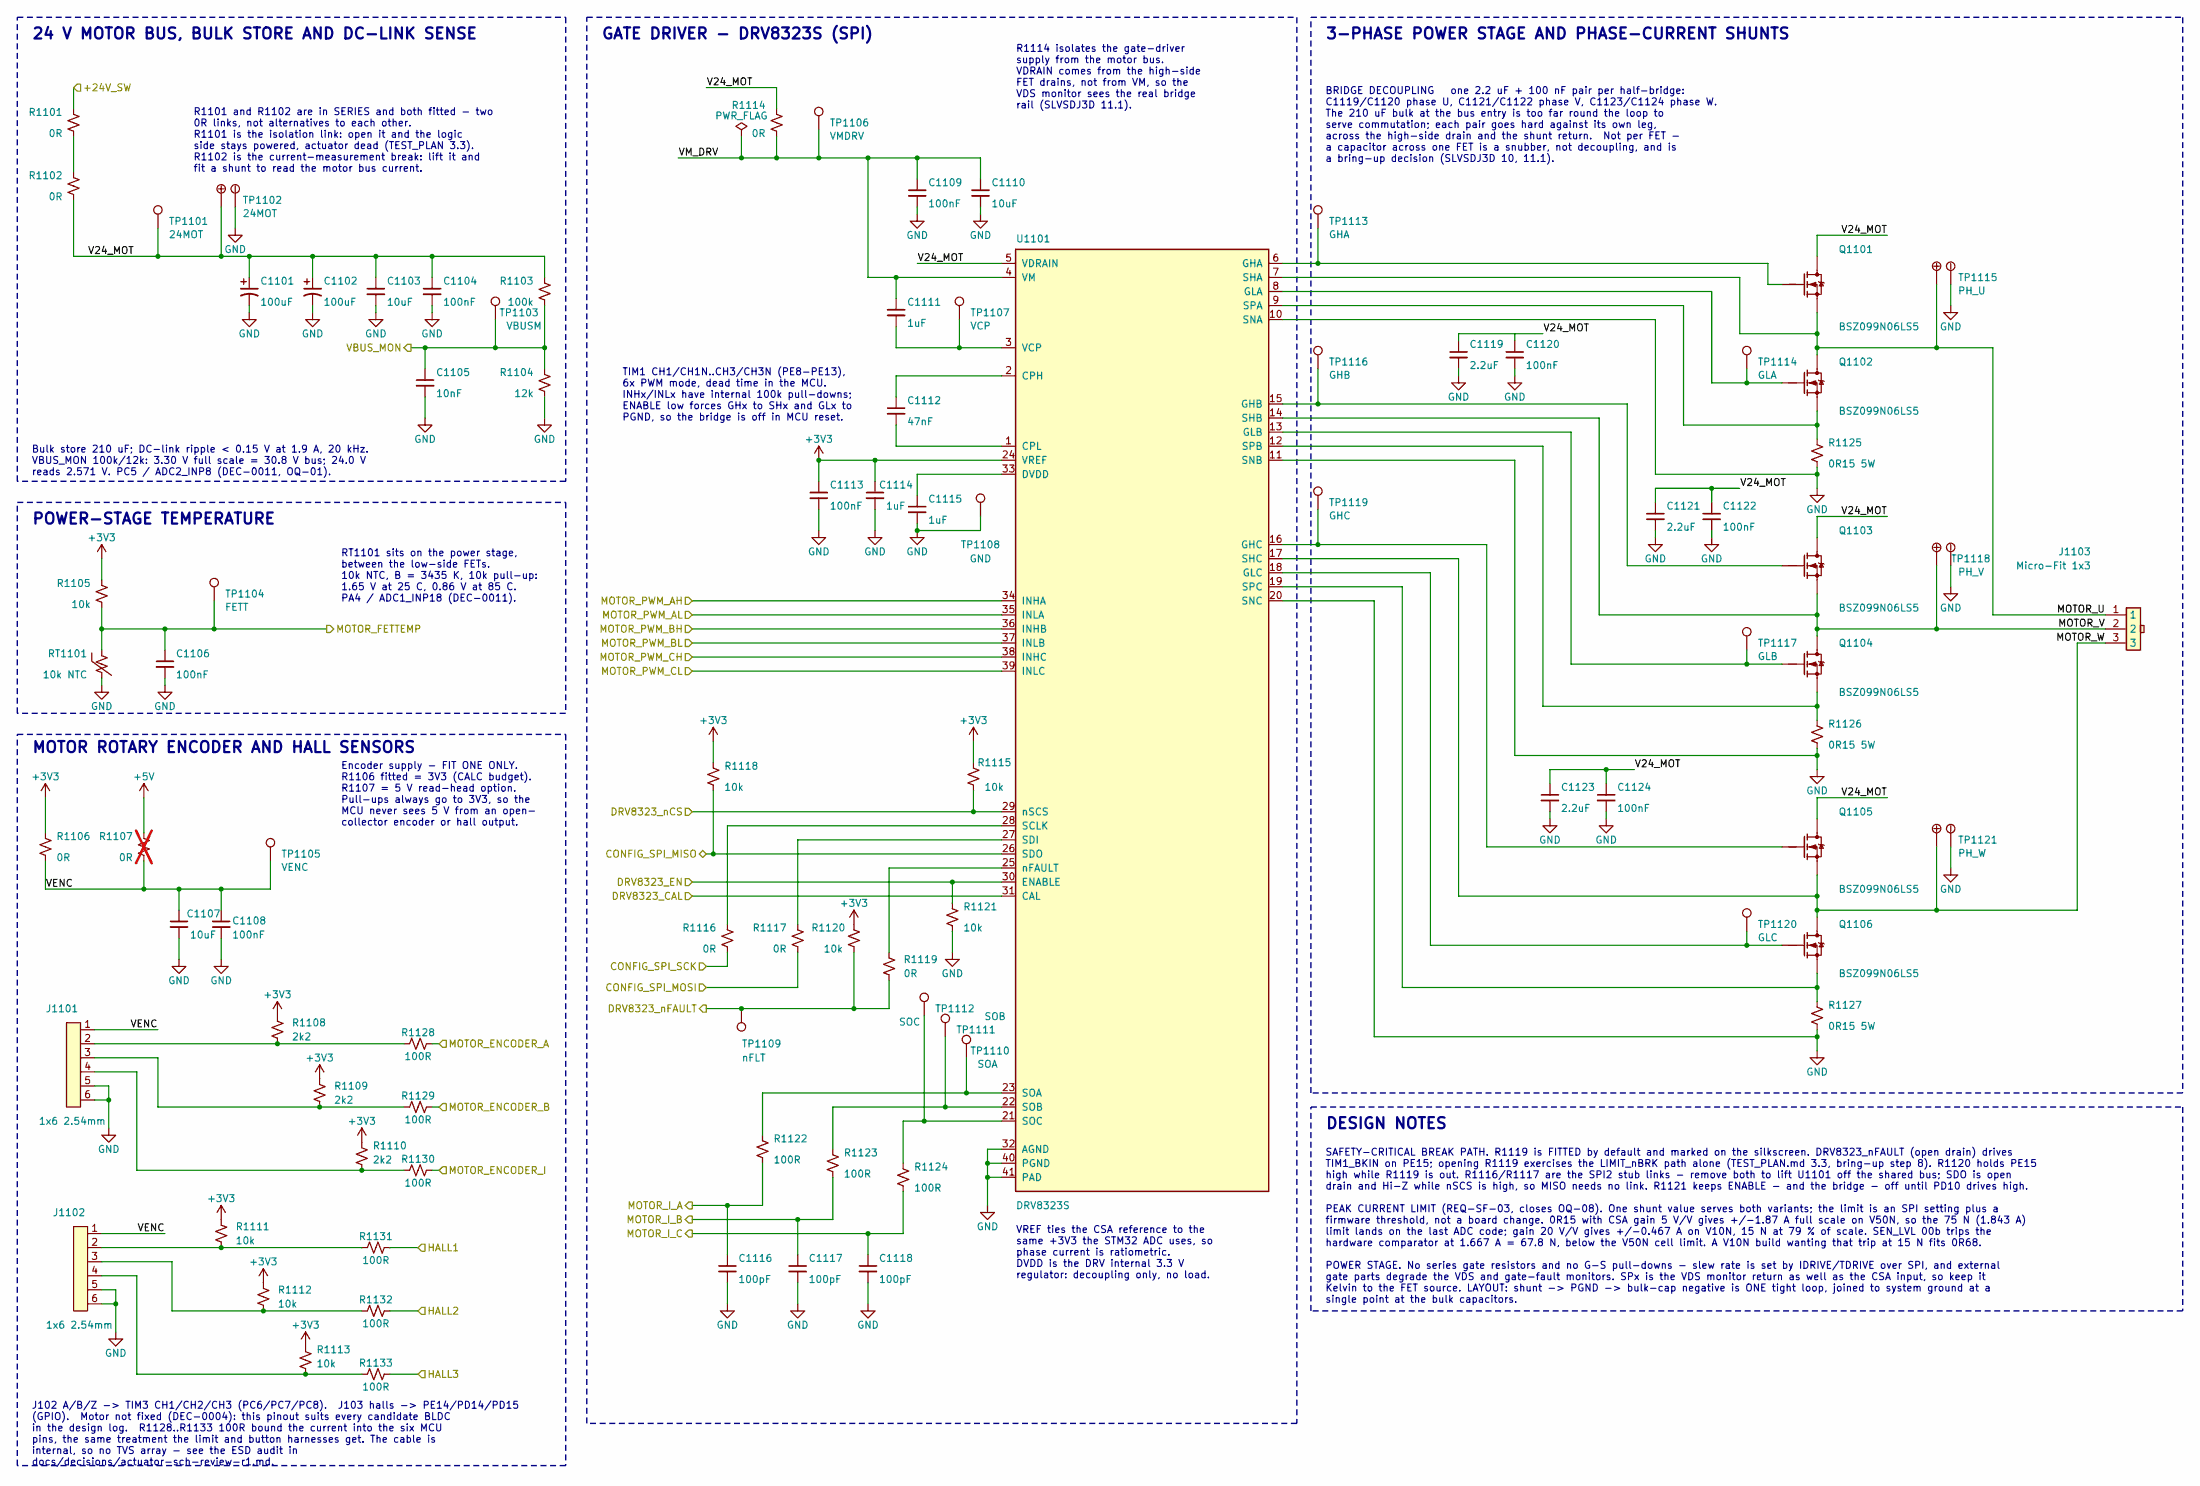
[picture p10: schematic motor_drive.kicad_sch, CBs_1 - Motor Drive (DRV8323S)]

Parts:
C1101, C1102: 100uF; C_ALU_D10_L10.2_SMT_ANTI-VIBE
C1103, C1110: 10uF; C_1210_3225Metric
C1104, C1109: 100nF; C_0805_2012Metric
C1105: 10nF; C_0603_1608Metric
C1106, C1108, C1113: 100nF; C_0402_1005Metric
C1107: 10uF; C_0805_2012Metric
C1111, C1114, C1115: 1uF; C_0603_1608Metric
C1112: 47nF; C_0603_1608Metric
C1116, C1117, C1118: 100pF; C_0603_1608Metric
C1119, C1121, C1123: 2.2uF; C_1206_3216Metric; mpn KAM31GR72A225KU
C1120, C1122, C1124: 100nF; C_0805_2012Metric; Voltage 100V; mpn 08051C104K4T4A
J1101, J1102: 1x6 2.54mm; Adam_Tech_PH1-06-UA
J1103: Micro-Fit 1x3; 436500327
Q1101, Q1102, Q1103, Q1104, Q1105, Q1106: BSZ099N06LS5; PG-TSDSON-8-32
R1101, R1102, R1114: 0R; R_1206_3216Metric
R1103: 100k; R_0603_1608Metric
R1104: 12k; R_0603_1608Metric
R1105, R1111, R1112, R1113, R1115, R1118, R1120, R1121: 10k; R_0603_1608Metric
R1106, R1116, R1117, R1119: 0R; R_0603_1608Metric
R1107: 0R; R_0603_1608Metric; not fitted
R1108, R1109, R1110: 2k2; R_0603_1608Metric
R1122, R1123, R1124: 100R; R_0603_1608Metric
R1125, R1126, R1127: 0R15 5W; R_4527_11470Metric
R1128, R1129, R1130, R1131, R1132, R1133: 100R; R_0603_1608Metric; mpn ERJ-3EKF1000V
RT1101: 10k NTC; R_0603_1608Metric
TP1101: 24MOT; TestPoint_Pad_D1.0mm
TP1102: 24MOT; TestPoint_Dual_D1.5mm_H1.0mm
TP1103: VBUSM; TestPoint_Pad_D1.0mm
TP1104: FETT; TestPoint_Pad_D1.0mm
TP1105: VENC; TestPoint_Pad_D1.0mm
TP1106: VMDRV; TestPoint_Pad_D1.0mm
TP1107: VCP; TestPoint_Pad_D1.0mm
TP1108: GND; TestPoint_Pad_D1.0mm
TP1109: nFLT; KeystoneMiniatureTestLoop
TP1110: SOA; KeystoneMiniatureTestLoop
TP1111: SOB; KeystoneMiniatureTestLoop
TP1112: SOC; KeystoneMiniatureTestLoop
TP1113: GHA; KeystoneMiniatureTestLoop
TP1114: GLA; KeystoneMiniatureTestLoop
TP1115: PH_U; TestPoint_Dual_D1.5mm_H1.0mm
TP1116: GHB; KeystoneMiniatureTestLoop
TP1117: GLB; KeystoneMiniatureTestLoop
TP1118: PH_V; TestPoint_Dual_D1.5mm_H1.0mm
TP1119: GHC; KeystoneMiniatureTestLoop
TP1120: GLC; KeystoneMiniatureTestLoop
TP1121: PH_W; TestPoint_Dual_D1.5mm_H1.0mm
U1101: DRV8323S; Texas_RTA0040B_WQFN-40-1EP_6x6mm_P0.5mm_EP4.15x4.15mm

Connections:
+3V3: C1113.1, C1114.1, R1105.1, R1106.1, R1108.1, R1109.1, R1110.1, R1111.1, R1112.1, R1113.1, R1115.1, R1118.1, R1120.1, U1101.24 (VREF); also elsewhere on the board
+5V: R1107.1; also elsewhere on the board
/mcu/DRV8323_CAL: U1101.31 (CAL); also elsewhere on the board
/mcu/DRV8323_EN: R1121.1, U1101.30 (ENABLE); also elsewhere on the board
/mcu/DRV8323_nCS: R1115.2, U1101.29 (nSCS); also elsewhere on the board
/mcu/DRV8323_nFAULT: R1119.2, R1120.2, TP1109.1; also elsewhere on the board
/mcu/HALL1: R1131.2; also elsewhere on the board
/mcu/HALL2: R1132.2; also elsewhere on the board
/mcu/HALL3: R1133.2; also elsewhere on the board
/mcu/MOTOR_ENCODER_A: R1128.2; also elsewhere on the board
/mcu/MOTOR_ENCODER_B: R1129.2; also elsewhere on the board
/mcu/MOTOR_ENCODER_I: R1130.2; also elsewhere on the board
/mcu/MOTOR_FETTEMP: C1106.1, R1105.2, RT1101.1, TP1104.1; also elsewhere on the board
/mcu/MOTOR_I_A: C1116.1, R1122.2; also elsewhere on the board
/mcu/MOTOR_I_B: C1117.1, R1123.2; also elsewhere on the board
/mcu/MOTOR_I_C: C1118.1, R1124.2; also elsewhere on the board
/mcu/MOTOR_PWM_AH: U1101.34 (INHA); also elsewhere on the board
/mcu/MOTOR_PWM_AL: U1101.35 (INLA); also elsewhere on the board
/mcu/MOTOR_PWM_BH: U1101.36 (INHB); also elsewhere on the board
/mcu/MOTOR_PWM_BL: U1101.37 (INLB); also elsewhere on the board
/mcu/MOTOR_PWM_CH: U1101.38 (INHC); also elsewhere on the board
/mcu/MOTOR_PWM_CL: U1101.39 (INLC); also elsewhere on the board
/mcu/VBUS_MON: C1105.1, R1103.2, R1104.1, TP1103.1; also elsewhere on the board
/motor_drive/MOTOR_U: J1103.1, Q1101.1_2_3 (S_3), Q1102.5_6_7_8 (D_2), TP1115.1, U1101.7 (SHA)
/motor_drive/MOTOR_V: J1103.2, Q1103.1_2_3 (S_3), Q1104.5_6_7_8 (D_2), TP1118.1, U1101.14 (SHB)
/motor_drive/MOTOR_W: J1103.3, Q1105.1_2_3 (S_3), Q1106.5_6_7_8 (D_2), TP1121.1, U1101.17 (SHC)
/motor_drive/V24_MOT: C1101.1, C1102.1, C1103.1, C1104.1, C1119.1, C1120.1, C1121.1, C1122.1, C1123.1, C1124.1, Q1101.5_6_7_8 (D_2), Q1103.5_6_7_8 (D_2), Q1105.5_6_7_8 (D_2), R1102.2, R1103.1, R1114.1, TP1101.1, TP1102.1, U1101.5 (VDRAIN)
/motor_drive/VENC: C1107.1, C1108.1, J1101.1, J1102.1, R1106.2, R1107.2, TP1105.1
/motor_drive/VM_DRV: C1109.1, C1110.1, C1111.1, R1114.2, TP1106.1, U1101.4 (VM)
/power_entry_24v/+24V_SW: R1101.1; also elsewhere on the board
/temp_sense/CONFIG_SPI_MISO: R1118.2, U1101.26 (SDO); also elsewhere on the board
/temp_sense/CONFIG_SPI_MOSI: R1117.2; also elsewhere on the board
/temp_sense/CONFIG_SPI_SCK: R1116.2; also elsewhere on the board
GND: C1101.2, C1102.2, C1103.2, C1104.2, C1105.2, C1106.2, C1107.2, C1108.2, C1109.2, C1110.2, C1113.2, C1114.2, C1115.2, C1116.2, C1117.2, C1118.2, C1119.2, C1120.2, C1121.2, C1122.2, C1123.2, C1124.2, J1101.5, J1101.6, J1102.5, J1102.6, R1104.2, R1121.2, R1125.2, R1126.2, R1127.2, RT1101.2, TP1102.2, TP1108.1, TP1115.2, TP1118.2, TP1121.2, U1101.10 (SNA), U1101.11 (SNB), U1101.20 (SNC), U1101.32 (AGND), U1101.40 (PGND), U1101.41 (PAD); also elsewhere on the board
unnamed: J1101.2, R1108.2, R1128.1
unnamed: J1101.3, R1109.2, R1129.1
unnamed: J1101.4, R1110.2, R1130.1
unnamed: J1102.2, R1111.2, R1131.1
unnamed: J1102.3, R1112.2, R1132.1
unnamed: J1102.4, R1113.2, R1133.1
unnamed: Q1101.4 (G), TP1113.1, U1101.6 (GHA)
unnamed: Q1102.4 (G), TP1114.1, U1101.8 (GLA)
unnamed: Q1102.1_2_3 (S_3), R1125.1, U1101.9 (SPA)
unnamed: Q1103.4 (G), TP1116.1, U1101.15 (GHB)
unnamed: Q1104.4 (G), TP1117.1, U1101.13 (GLB)
unnamed: Q1104.1_2_3 (S_3), R1126.1, U1101.12 (SPB)
unnamed: Q1105.4 (G), TP1119.1, U1101.16 (GHC)
unnamed: Q1106.4 (G), TP1120.1, U1101.18 (GLC)
unnamed: Q1106.1_2_3 (S_3), R1127.1, U1101.19 (SPC)
unnamed: R1101.2, R1102.1
unnamed: C1112.1, U1101.2 (CPH)
unnamed: C1112.2, U1101.1 (CPL)
unnamed: C1115.1, U1101.33 (DVDD)
unnamed: R1116.1, U1101.28 (SCLK)
unnamed: R1117.1, U1101.27 (SDI)
unnamed: R1122.1, TP1110.1, U1101.23 (SOA)
unnamed: R1123.1, TP1111.1, U1101.22 (SOB)
unnamed: R1124.1, TP1112.1, U1101.21 (SOC)
unnamed: C1111.2, TP1107.1, U1101.3 (VCP)
unnamed: R1119.1, U1101.25 (nFAULT)

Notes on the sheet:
BRIDGE DECOUPLING one 2.2 uF + 100 nF pair per half-bridge: C1119/C1120 phase U, C1121/C1122 phase V, C1123/C1124 phase W. The 210 uF bulk at the bus entry is too far round the loop to serve commutation; each pair goes hard against its own leg, across the high-side drain and the shunt return. Not p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
Bulk store 210 uF; DC-link ripple < 0.15 V at 1.9 A, 20 kHz. VBUS_MON 100k/12k: 3.30 V full scale = 30.8 V bus; 24.0 V reads 2.571 V. PC5 / ADC2_INP8 (DEC-0011, OQ-01).
SAFETY-CRITICAL BREAK PATH. R1119 is FITTED by default and marked on the silkscreen. DRV8323_nFAULT (open drain) drives TIM1_BKIN on PE15; opening R1119 exercises the LIMIT_nBRK path alone (TEST_PLAN.md 3.3, bring-up step 8). R1120 holds PE15 high while R1119 is out. R1116/R1117 are the SPI2 stub l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
RT1101 sits on the power stage, between the low-side FETs. 10k NTC, B = 3435 K, 10k pull-up: 1.65 V at 25 C, 0.86 V at 85 C. PA4 / ADC1_INP18 (DEC-0011).
Encoder supply - FIT ONE ONLY. R1106 fitted = 3V3 (CALC budget). R1107 = 5 V read-head option. Pull-ups always go to 3V3, so the MCU never sees 5 V from an open- collector encoder or hall output.
J102 A/B/Z -> TIM3 CH1/CH2/CH3 (PC6/PC7/PC8). J103 halls -> PE14/PD14/PD15 (GPIO). Motor not fixed (DEC-0004): this pinout suits every candidate BLDC in the design log. R1128..R1133 100R bound the current into the six MCU pins, the same treatment the limit and button harnesses get. The cable is int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
MOTOR ROTARY ENCODER AND HALL SENSORS
R1101 and R1102 are in SERIES and both fitted - two 0R links, not alternatives to each other. R1101 is the isolation link: open it and the logic side stays powered, actuator dead (TEST_PLAN 3.3). R1102 is the current-measurement break: lift it and fit a shunt to read the motor bus current.
DESIGN NOTES
24 V MOTOR BUS, BULK STORE AND DC-LINK SENSE
TIM1 CH1/CH1N..CH3/CH3N (PE8-PE13), 6x PWM mode, dead time in the MCU. INHx/INLx have internal 100k pull-downs; ENABLE low forces GHx to SHx and GLx to PGND, so the bridge is off in MCU reset.
POWER-STAGE TEMPERATURE
VREF ties the CSA reference to the same +3V3 the STM32 ADC uses, so phase current is ratiometric. DVDD is the DRV internal 3.3 V regulator: decoupling only, no load.
R1114 isolates the gate-driver supply from the motor bus. VDRAIN comes from the high-side FET drains, not from VM, so the VDS monitor sees the real bridge rail (SLVSDJ3D 11.1).
GATE DRIVER - DRV8323S (SPI)
3-PHASE POWER STAGE AND PHASE-CURRENT SHUNTS

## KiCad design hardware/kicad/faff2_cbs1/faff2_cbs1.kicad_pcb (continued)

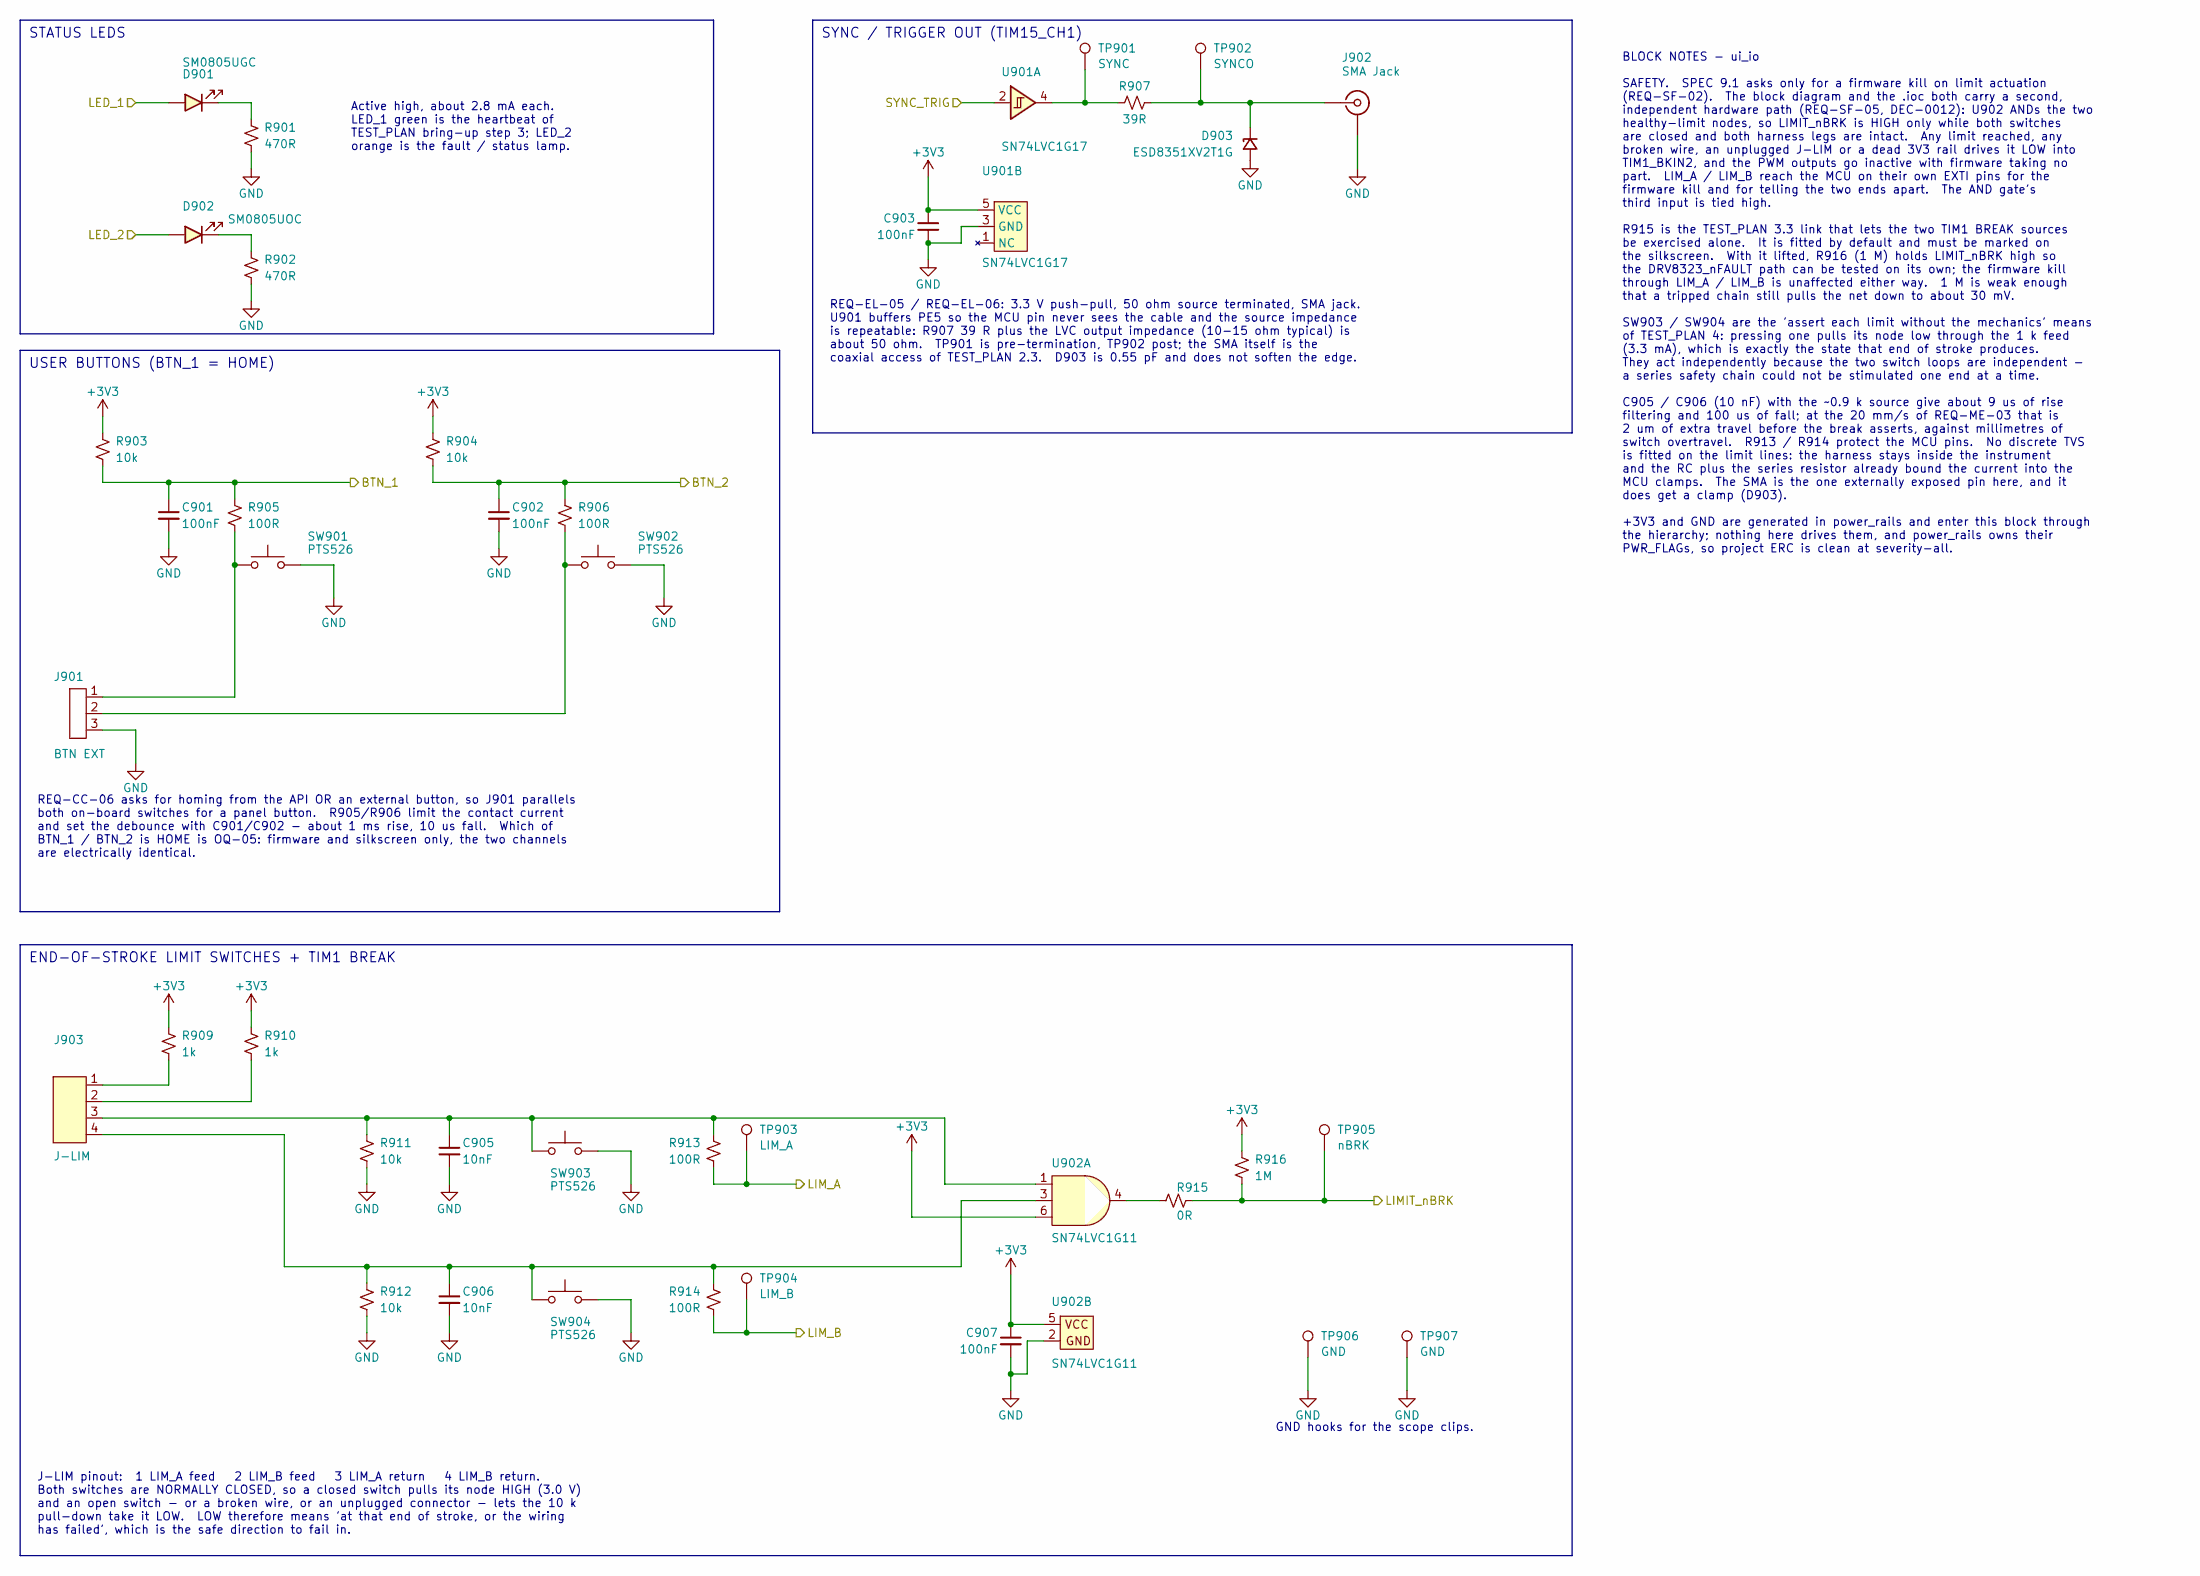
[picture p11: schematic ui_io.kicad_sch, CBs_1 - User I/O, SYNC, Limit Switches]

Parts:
C901, C902, C903, C907: 100nF; C_0603_1608Metric; mpn C0603C104M5RACAUTO
C905, C906: 10nF; C_0603_1608Metric; mpn C0603C103M5RACAUTO
D901: SM0805UGC; LED 0805 SM0805; mpn SM0805UGC
D902: SM0805UOC; LED 0805 SM0805; mpn SM0805UOC
D903: ESD8351XV2T1G; SC-79 (SOD523); mpn ESD8351XV2T1G
J901: BTN EXT; 87224-3; mpn 87224-3
J902: SMA Jack; SMA-J-P-H-ST-TH1; mpn SMA-J-P-H-ST-TH1
J903: J-LIM; B4B-XH-AM; mpn B4B-XH-AM
R901, R902: 470R; R_0603_1608Metric; mpn ERJ-3EKF4700V
R903, R904, R911, R912: 10k; R_0603_1608Metric; mpn ERJ-3EKF1002V
R905, R906, R913, R914: 100R; R_0603_1608Metric; mpn ERJ-3EKF1000V
R907: 39R; R_0603_1608Metric; mpn ERJ-3EKF39R0V
R909, R910: 1k; R_0603_1608Metric; mpn CR0603AFX-1001ELF
R915: 0R; R_0603_1608Metric; mpn RC0603FR-070RL
R916: 1M; R_0603_1608Metric; mpn ERJ-3EKF1004V
SW901, SW902, SW903, SW904: PTS526; PTS526_1.5mm_G; mpn PTS526 SK15 SMTR2 LFS
TP901: SYNC; KeystoneMiniatureTestLoop; mpn 5002
TP902: SYNCO; TestPoint_Pad_D1.0mm
TP903: LIM_A; KeystoneMiniatureTestLoop; mpn 5002
TP904: LIM_B; KeystoneMiniatureTestLoop; mpn 5002
TP905: nBRK; KeystoneMiniatureTestLoop; mpn 5002
TP906, TP907: GND; KeystoneMiniatureTestLoop; mpn 5002
U901: SN74LVC1G17; SOT23-5 - TI; mpn SN74LVC1G17DBVRG4
U902: SN74LVC1G11; SOT23-6; mpn SN74LVC1G11DBVR

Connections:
+3V3: C903.1, C907.1, R903.1, R904.1, R909.1, R910.1, R916.1, U901.5 (VCC), U902.5 (VCC), U902.6 (C); also elsewhere on the board
/mcu/BTN_1: C901.1, R903.2, R905.1; also elsewhere on the board
/mcu/BTN_2: C902.1, R904.2, R906.1; also elsewhere on the board
/mcu/LED_1: D901.1; also elsewhere on the board
/mcu/LED_2: D902.1; also elsewhere on the board
/mcu/LIMIT_nBRK: R915.2, R916.2, TP905.1; also elsewhere on the board
/mcu/LIM_A: R913.2, TP903.1; also elsewhere on the board
/mcu/LIM_B: R914.2, TP904.1; also elsewhere on the board
/mcu/SYNC_TRIG: U901.2; also elsewhere on the board
GND: C901.2, C902.2, C903.2, C905.2, C906.2, C907.2, D903.2 (A), J901.3, J902.2 (Ext), R901.2, R902.2, R911.2, R912.2, SW901.3_4, SW902.3_4, SW903.3_4, SW904.3_4, TP906.1, TP907.1, U901.3 (GND), U902.2 (GND); also elsewhere on the board
unnamed: D901.2, R901.1
unnamed: D902.2, R902.1
unnamed: D903.1 (K), J902.1 (In), R907.2, TP902.1
unnamed: J901.1, R905.2, SW901.1_2
unnamed: J901.2, R906.2, SW902.1_2
unnamed: J903.1, R909.2
unnamed: J903.2, R910.2
unnamed: R907.1, TP901.1, U901.4
unnamed: C905.1, J903.3, R911.1, R913.1, SW903.1_2, U902.1 (A)
unnamed: C906.1, J903.4, R912.1, R914.1, SW904.1_2, U902.3 (B)
unnamed: R915.1, U902.4 (Y)

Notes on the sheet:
GND hooks for the scope clips.
J-LIM pinout: 1 LIM_A feed 2 LIM_B feed 3 LIM_A return 4 LIM_B return. Both switches are NORMALLY CLOSED, so a closed switch pulls its node HIGH (3.0 V) and an open switch - or a broken wire, or an unplugged connector - lets the 10 k pull-down take it LOW. LOW therefore means 'at that end of stroke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
STATUS LEDS
REQ-EL-05 / REQ-EL-06: 3.3 V push-pull, 50 ohm source terminated, SMA jack. U901 buffers PE5 so the MCU pin never sees the cable and the source impedance is repeatable: R907 39 R plus the LVC output impedance (10-15 ohm typical) is about 50 ohm. TP901 is pre-termination, TP902 post; the SMA itself 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
END-OF-STROKE LIMIT SWITCHES + TIM1 BREAK
BLOCK NOTES - ui_io SAFETY. SPEC 9.1 asks only for a firmware kill on limit actuation (REQ-SF-02). The block diagram and the .ioc both carry a second, independent hardware path (REQ-SF-05, DEC-0012): U902 ANDs the two healthy-limit nodes, so LIMIT_nBRK is HIGH only while both switches are closed an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
Active high, about 2.8 mA each. LED_1 green is the heartbeat of TEST_PLAN bring-up step 3; LED_2 orange is the fault / status lamp.
USER BUTTONS (BTN_1 = HOME)
REQ-CC-06 asks for homing from the API OR an external button, so J901 parallels both on-board switches for a panel button. R905/R906 limit the contact current and set the debounce with C901/C902 - about 1 ms rise, 10 us fall. Which of BTN_1 / BTN_2 is HOME is OQ-05: firmware and silkscreen only, th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
SYNC / TRIGGER OUT (TIM15_CH1)

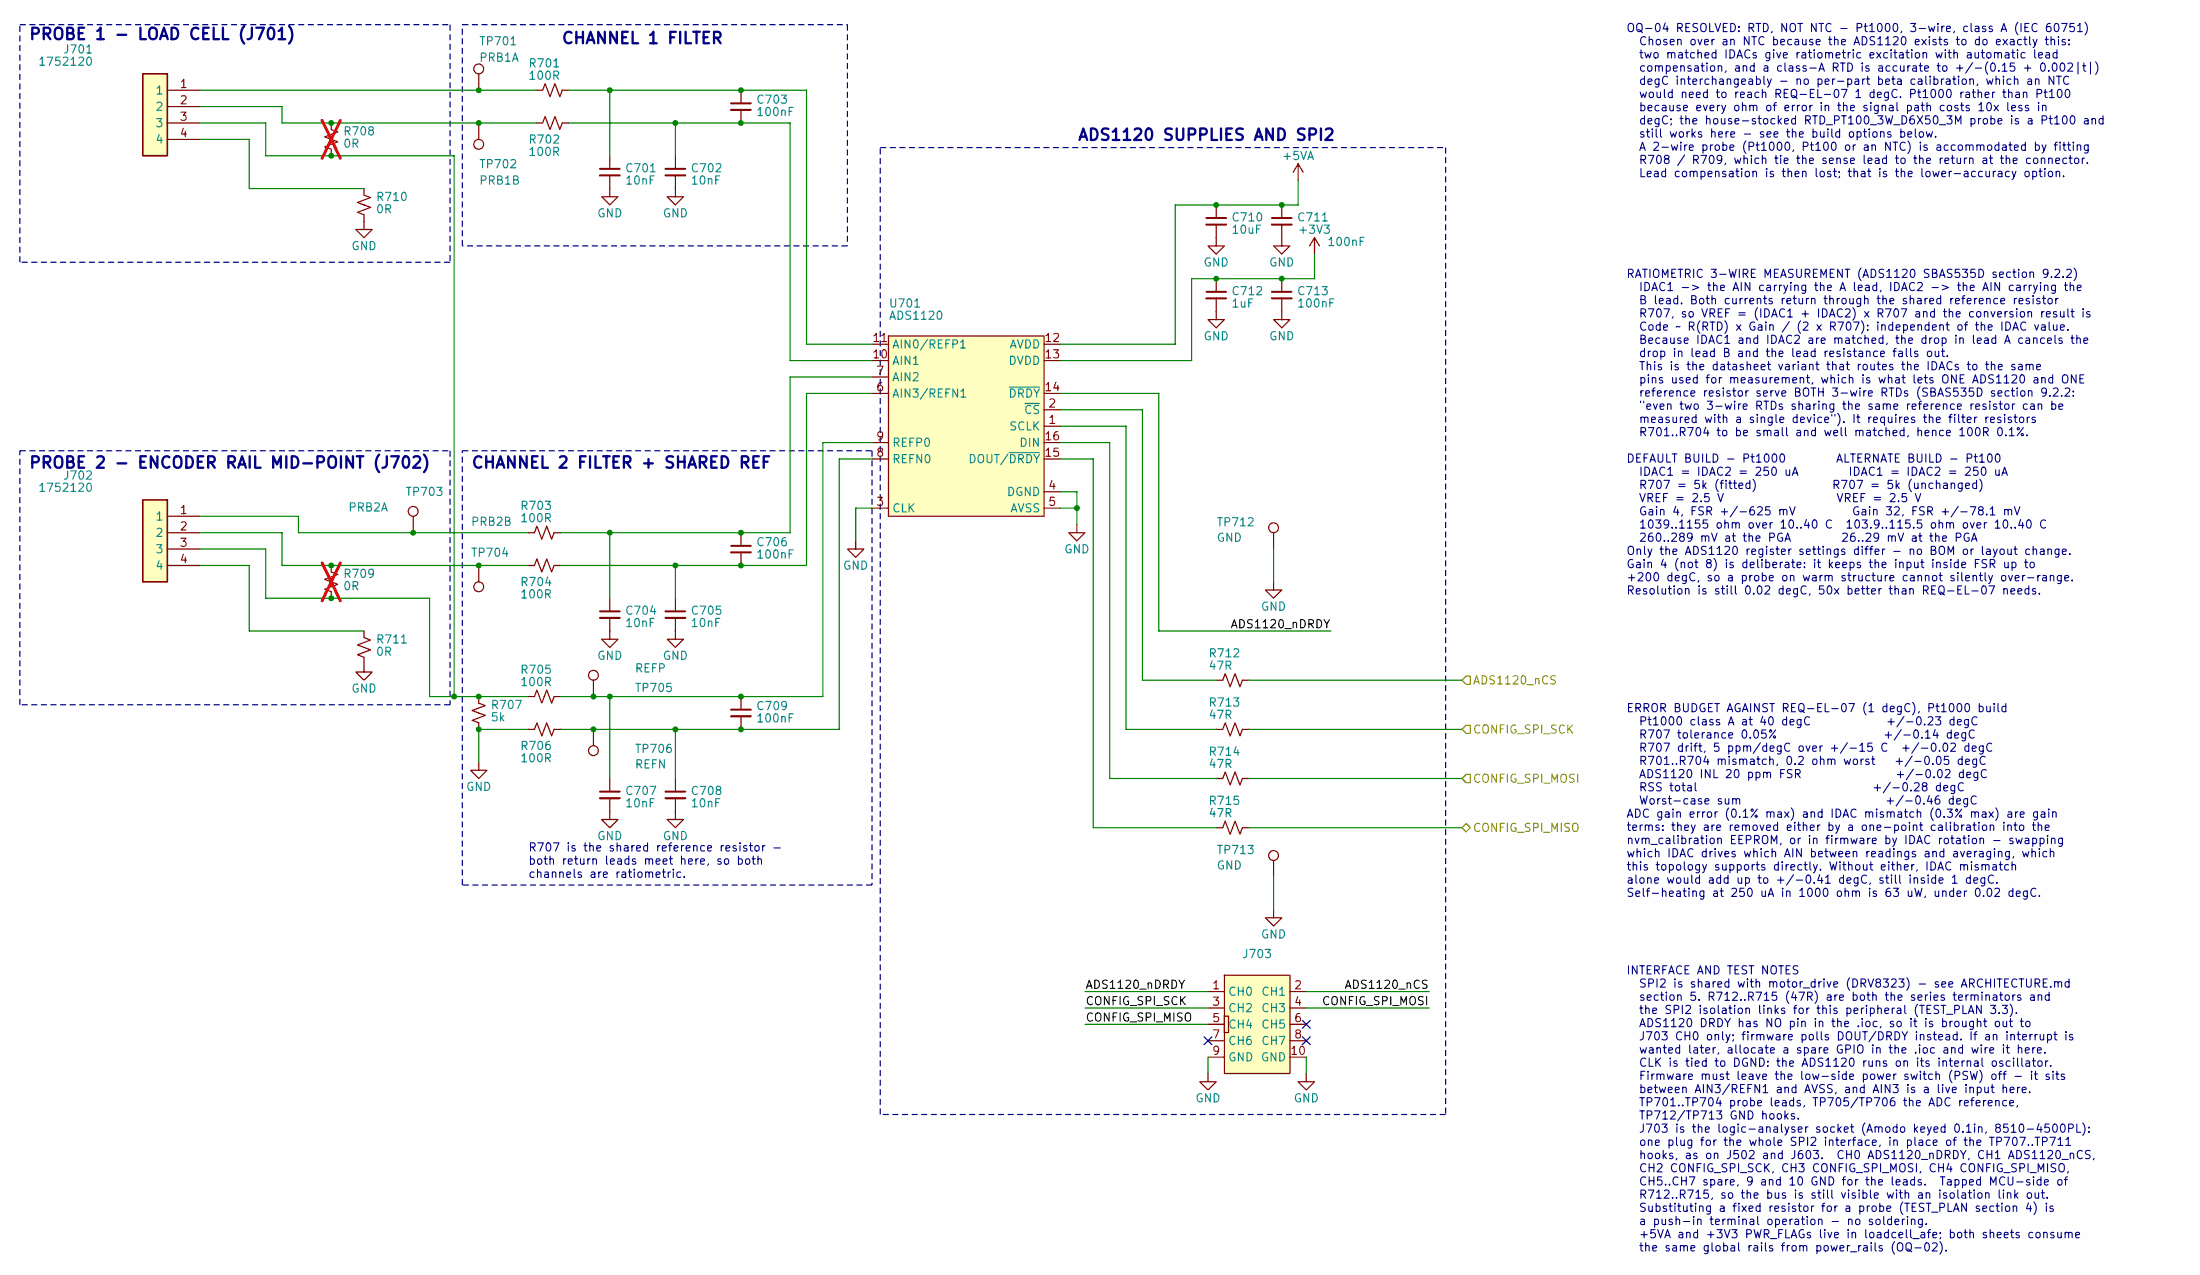
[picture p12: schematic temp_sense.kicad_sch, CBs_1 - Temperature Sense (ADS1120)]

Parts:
C701, C702, C704, C705, C707, C708: 10nF; C_0603_1608Metric; mpn CGA3EAC0G2A103J080AC
C703, C706, C709, C711, C713: 100nF; C_0402_1005Metric; mpn 04025C104KAT2A
C710: 10uF; C_0805_2012Metric; mpn GRM21BR61E106MA73L
C712: 1uF; C_0603_1608Metric; mpn CL10B105KO8NNNC
J701, J702: 1752120; SHDR4W100P0X350_1X4_1460X1000X1240P; mpn 1752120
J703: 8510-4500PL; 8510-4500PL_LOGIC_TEST; mpn 8510-4500PL
R701, R702, R703, R704, R705, R706: 100R; R_0603_1608Metric; mpn ERA3AEB101V
R707: 5k; R_0805_2012Metric; mpn PLT0805Z5001AST5
R708, R709: 0R; R_0603_1608Metric; mpn RC0603FR-070RL; not fitted
R710, R711: 0R; R_0603_1608Metric; mpn RC0603FR-070RL
R712, R713, R714, R715: 47R; R_0603_1608Metric; mpn ERJ-3EKF47R0V
TP701: PRB1A; TestPoint_Pad_D1.0mm
TP702: PRB1B; TestPoint_Pad_D1.0mm
TP703: PRB2A; TestPoint_Pad_D1.0mm
TP704: PRB2B; TestPoint_Pad_D1.0mm
TP705: REFP; TestPoint_Pad_D1.0mm
TP706: REFN; TestPoint_Pad_D1.0mm
TP712, TP713: GND; KeystoneMiniatureTestLoop; mpn 5002
U701: ADS1120; TSSOP-16; mpn ADS1120IPWR

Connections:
+3V3: C712.1, C713.1, U701.13 (DVDD); also elsewhere on the board
+5VA: C710.1, C711.1, U701.12 (AVDD); also elsewhere on the board
/temp_sense/ADS1120_nCS: J703.2 (CH1), R712.2; also elsewhere on the board
/temp_sense/ADS1120_nDRDY: J703.1 (CH0), U701.14 (~DRDY)
/temp_sense/CONFIG_SPI_MISO: J703.5 (CH4), R715.2; also elsewhere on the board
/temp_sense/CONFIG_SPI_MOSI: J703.4 (CH3), R714.2; also elsewhere on the board
/temp_sense/CONFIG_SPI_SCK: J703.3 (CH2), R713.2; also elsewhere on the board
GND: C701.2, C702.2, C704.2, C705.2, C707.2, C708.2, C710.2, C711.2, C712.2, C713.2, J703.9 (GND), J703.10 (GND), R706.1, R707.2, R710.2, R711.2, TP712.1, TP713.1, U701.3 (CLK), U701.4 (DGND), U701.5 (AVSS); also elsewhere on the board
unnamed: J701.1, R701.1, TP701.1
unnamed: J701.2, R702.1, R708.1, TP702.1
unnamed: J701.3, J702.3, R705.1, R707.1, R708.2, R709.2
unnamed: J701.4, R710.1
unnamed: J702.1, R703.1, TP703.1
unnamed: J702.2, R704.1, R709.1, TP704.1
unnamed: J702.4, R711.1
unnamed: C701.1, C703.1, R701.2, U701.11 (AIN0/REFP1)
unnamed: C702.1, C703.2, R702.2, U701.10 (AIN1)
unnamed: C704.1, C706.1, R703.2, U701.7 (AIN2)
unnamed: C705.1, C706.2, R704.2, U701.6 (AIN3/REFN1)
unnamed: R714.1, U701.16 (DIN)
unnamed: R715.1, U701.15 (DOUT/~DRDY)
unnamed: C708.1, C709.2, R706.2, TP706.1, U701.8 (REFN0)
unnamed: C707.1, C709.1, R705.2, TP705.1, U701.9 (REFP0)
unnamed: R713.1, U701.1 (SCLK)
unnamed: R712.1, U701.2 (~CS)

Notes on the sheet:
ERROR BUDGET AGAINST REQ-EL-07 (1 degC), Pt1000 build Pt1000 class A at 40 degC +/-0.23 degC R707 tolerance 0.05% +/-0.14 degC R707 drift, 5 ppm/degC over +/-15 C +/-0.02 degC R701..R704 mismatch, 0.2 ohm worst +/-0.05 degC ADS1120 INL 20 ppm FSR +/-0.02 degC RSS total +/-0.28 degC Worst-case sum +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
ADS1120 SUPPLIES AND SPI2
RATIOMETRIC 3-WIRE MEASUREMENT (ADS1120 SBAS535D section 9.2.2) IDAC1 -> the AIN carrying the A lead, IDAC2 -> the AIN carrying the B lead. Both currents return through the shared reference resistor R707, so VREF = (IDAC1 + IDAC2) x R707 and the conversion result is Code ~ R(RTD) x Gain / (2 x R707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
PROBE 2 - ENCODER RAIL MID-POINT (J702)
OQ-04 RESOLVED: RTD, NOT NTC - Pt1000, 3-wire, class A (IEC 60751) Chosen over an NTC because the ADS1120 exists to do exactly this: two matched IDACs give ratiometric excitation with automatic lead compensation, and a class-A RTD is accurate to +/-(0.15 + 0.002|t|) degC interchangeably - no per-pa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
PROBE 1 - LOAD CELL (J701)
R707 is the shared reference resistor - both return leads meet here, so both channels are ratiometric.
CHANNEL 2 FILTER + SHARED REF
CHANNEL 1 FILTER
INTERFACE AND TEST NOTES SPI2 is shared with motor_drive (DRV8323) - see ARCHITECTURE.md section 5. R712..R715 (47R) are both the series terminators and the SPI2 isolation links for this peripheral (TEST_PLAN 3.3). ADS1120 DRDY has NO pin in the .ioc, so it is brought out to J703 CH0 only; firmware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

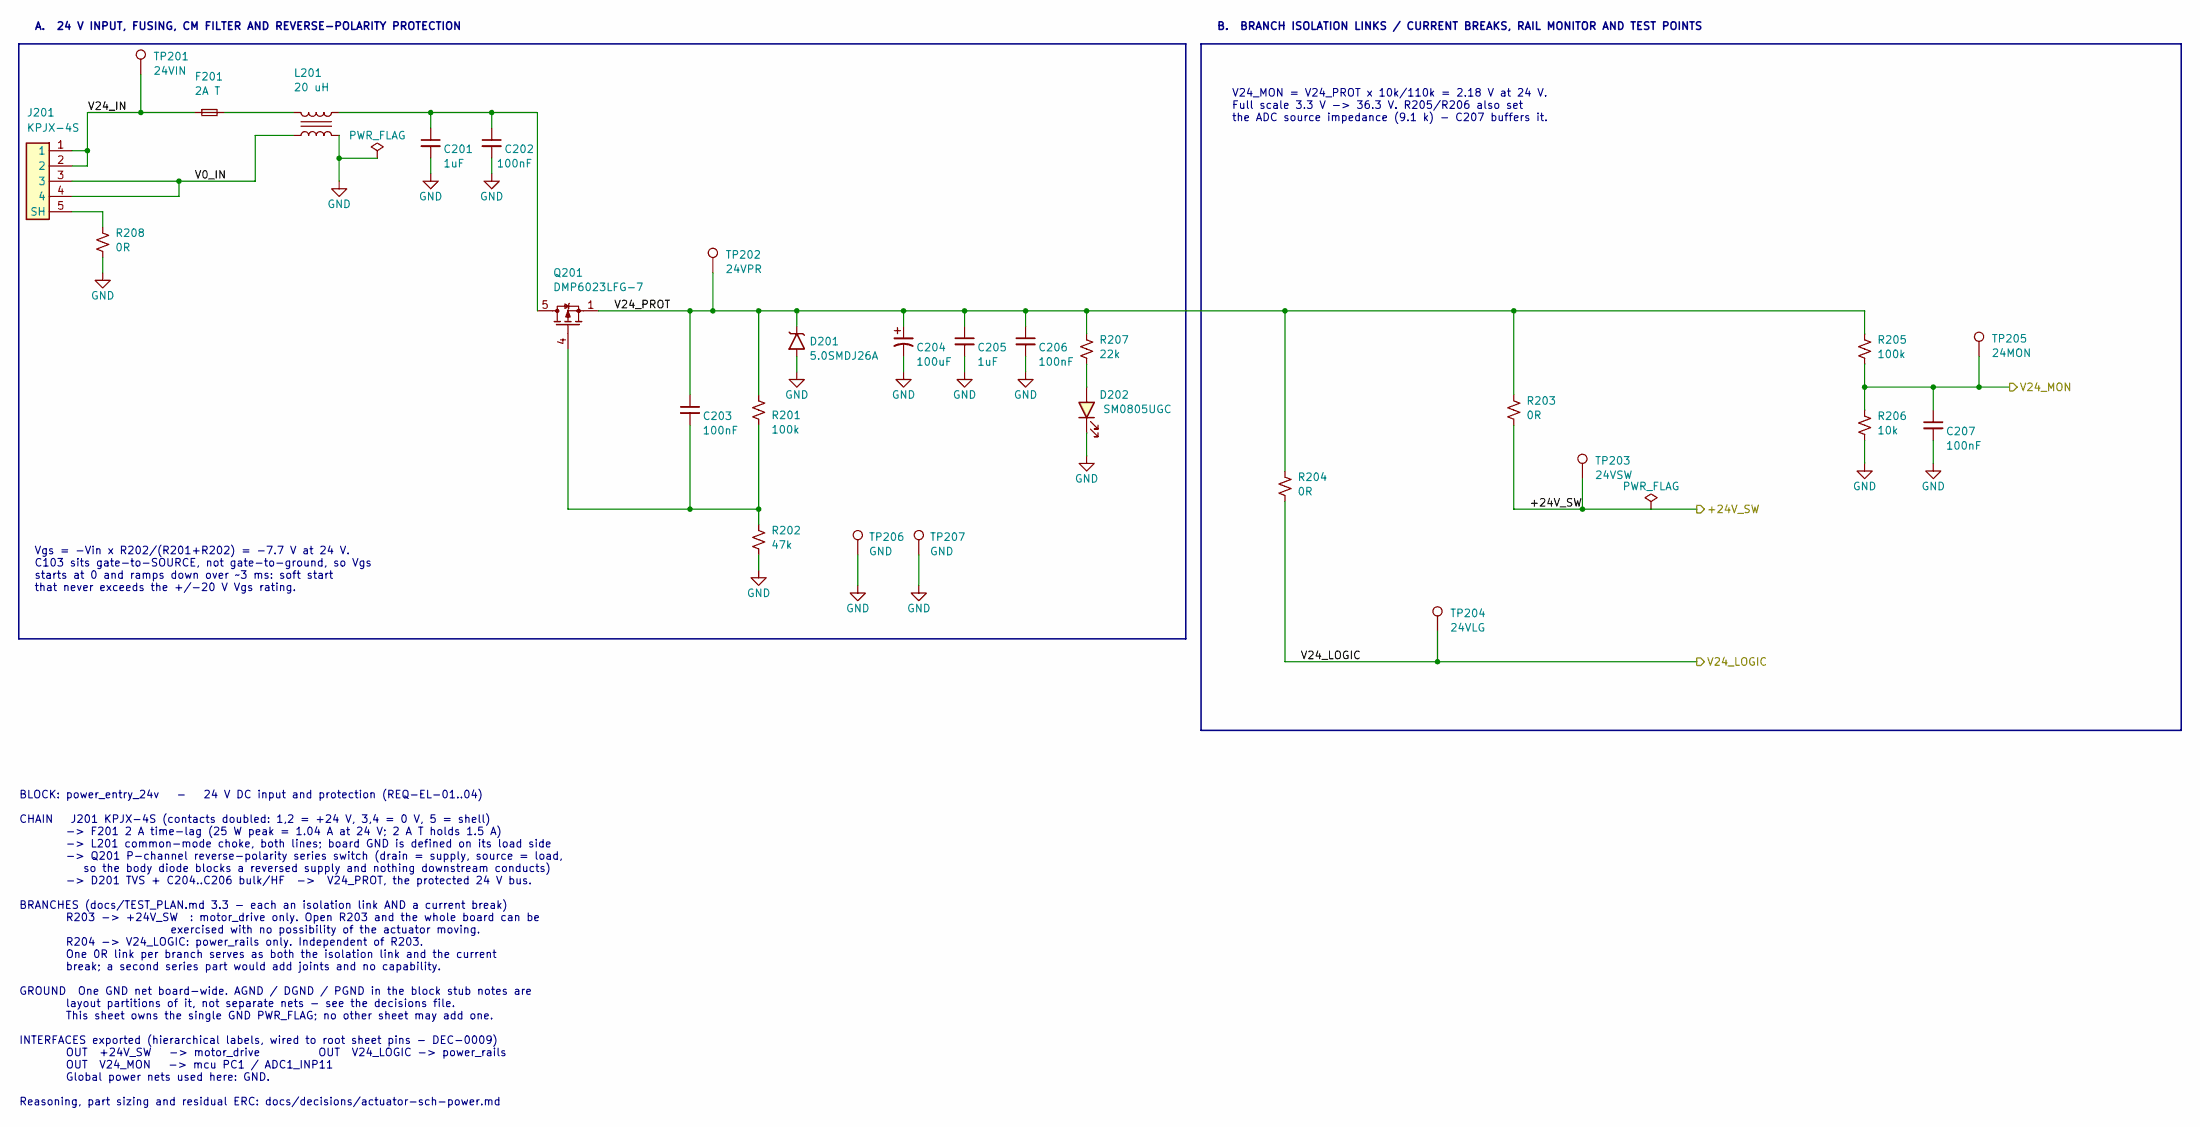
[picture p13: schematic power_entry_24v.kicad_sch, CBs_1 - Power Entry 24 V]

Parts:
C201, C205: 1uF; C_0805_2012Metric; Voltage 100V; mpn GRJ21BC72A105KE11L
C202, C206: 100nF; C_0805_2012Metric; Voltage 100V; mpn 08051C104K4T4A
C203, C207: 100nF; C_0603_1608Metric; mpn C0603C104M5RACAUTO
C204: 100uF; C_ALU_D10_L10.2_SMT_ANTI-VIBE; Voltage 63V; mpn EEE-FK1J101V
D201: 5.0SMDJ26A; DO-214AB; mpn 5.0SMDJ26A
D202: SM0805UGC; LED 0805 SM0805; mpn SM0805UGC
F201: 2A T; FUSE_157T_LittelFuse; mpn 0157002.DRT
J201: KPJX-4S; mpn KPJX-4S
L201: 20 uH; PLT10HH101150PN#; mpn PLT10HH1026R0PN#
Q201: DMP6023LFG-7; DMP4013LFG7; mpn DMP6023LFG-7
R201, R205: 100k; R_0603_1608Metric; mpn ERJ-3EKF1003V
R202: 47k; R_0603_1608Metric; mpn ERJ-3EKF4702V
R203, R204: 0R; R_1206_3216Metric; mpn PT1206-R-070RL
R206: 10k; R_0603_1608Metric; mpn ERJ-3EKF1002V
R207: 22k; R_0603_1608Metric; mpn ERJ-3EKF2202V
R208: 0R; R_0603_1608Metric; mpn RC0603FR-070RL
TP201: 24VIN; KeystoneMiniatureTestLoop; mpn 5002
TP202: 24VPR; KeystoneMiniatureTestLoop; mpn 5002
TP203: 24VSW; KeystoneMiniatureTestLoop; mpn 5002
TP204: 24VLG; KeystoneMiniatureTestLoop; mpn 5002
TP205: 24MON; TestPoint_Pad_D1.0mm
TP206, TP207: GND; KeystoneMiniatureTestLoop; mpn 5002

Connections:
/mcu/V24_MON: C207.1, R205.2, R206.1, TP205.1; also elsewhere on the board
/power_entry_24v/+24V_SW: R203.2, TP203.1; also elsewhere on the board
/power_entry_24v/V0_IN: J201.3, J201.4, L201.4
/power_entry_24v/V24_IN: F201.1, J201.1, J201.2, TP201.1
/power_entry_24v/V24_LOGIC: R204.2, TP204.1; also elsewhere on the board
/power_entry_24v/V24_PROT: C203.1, C204.1, C205.1, C206.1, D201.2 (A2), Q201.1 (S), R201.1, R203.1, R204.1, R205.1, R207.1, TP202.1
GND: C201.2, C202.2, C204.2, C205.2, C206.2, C207.2, D201.1 (A1), D202.2, L201.3, R202.2, R206.2, R208.2, TP206.1, TP207.1; also elsewhere on the board
unnamed: D202.1, R207.2
unnamed: F201.2, L201.1
unnamed: J201.5 (SH), R208.1
unnamed: C201.1, C202.1, L201.2, Q201.5 (D)
unnamed: C203.2, Q201.4 (G), R201.2, R202.1

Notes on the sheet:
Vgs = -Vin x R202/(R201+R202) = -7.7 V at 24 V. C103 sits gate-to-SOURCE, not gate-to-ground, so Vgs starts at 0 and ramps down over ~3 ms: soft start that never exceeds the +/-20 V Vgs rating.
A. 24 V INPUT, FUSING, CM FILTER AND REVERSE-POLARITY PROTECTION
BLOCK: power_entry_24v - 24 V DC input and protection (REQ-EL-01..04) CHAIN J201 KPJX-4S (contacts doubled: 1,2 = +24 V, 3,4 = 0 V, 5 = shell) -> F201 2 A time-lag (25 W peak = 1.04 A at 24 V; 2 A T holds 1.5 A) -> L201 common-mode choke, both lines; board GND is defined on its load side -> Q201 P-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
V24_MON = V24_PROT x 10k/110k = 2.18 V at 24 V. Full scale 3.3 V -> 36.3 V. R205/R206 also set the ADC source impedance (9.1 k) - C207 buffers it.
B. BRANCH ISOLATION LINKS / CURRENT BREAKS, RAIL MONITOR AND TEST POINTS

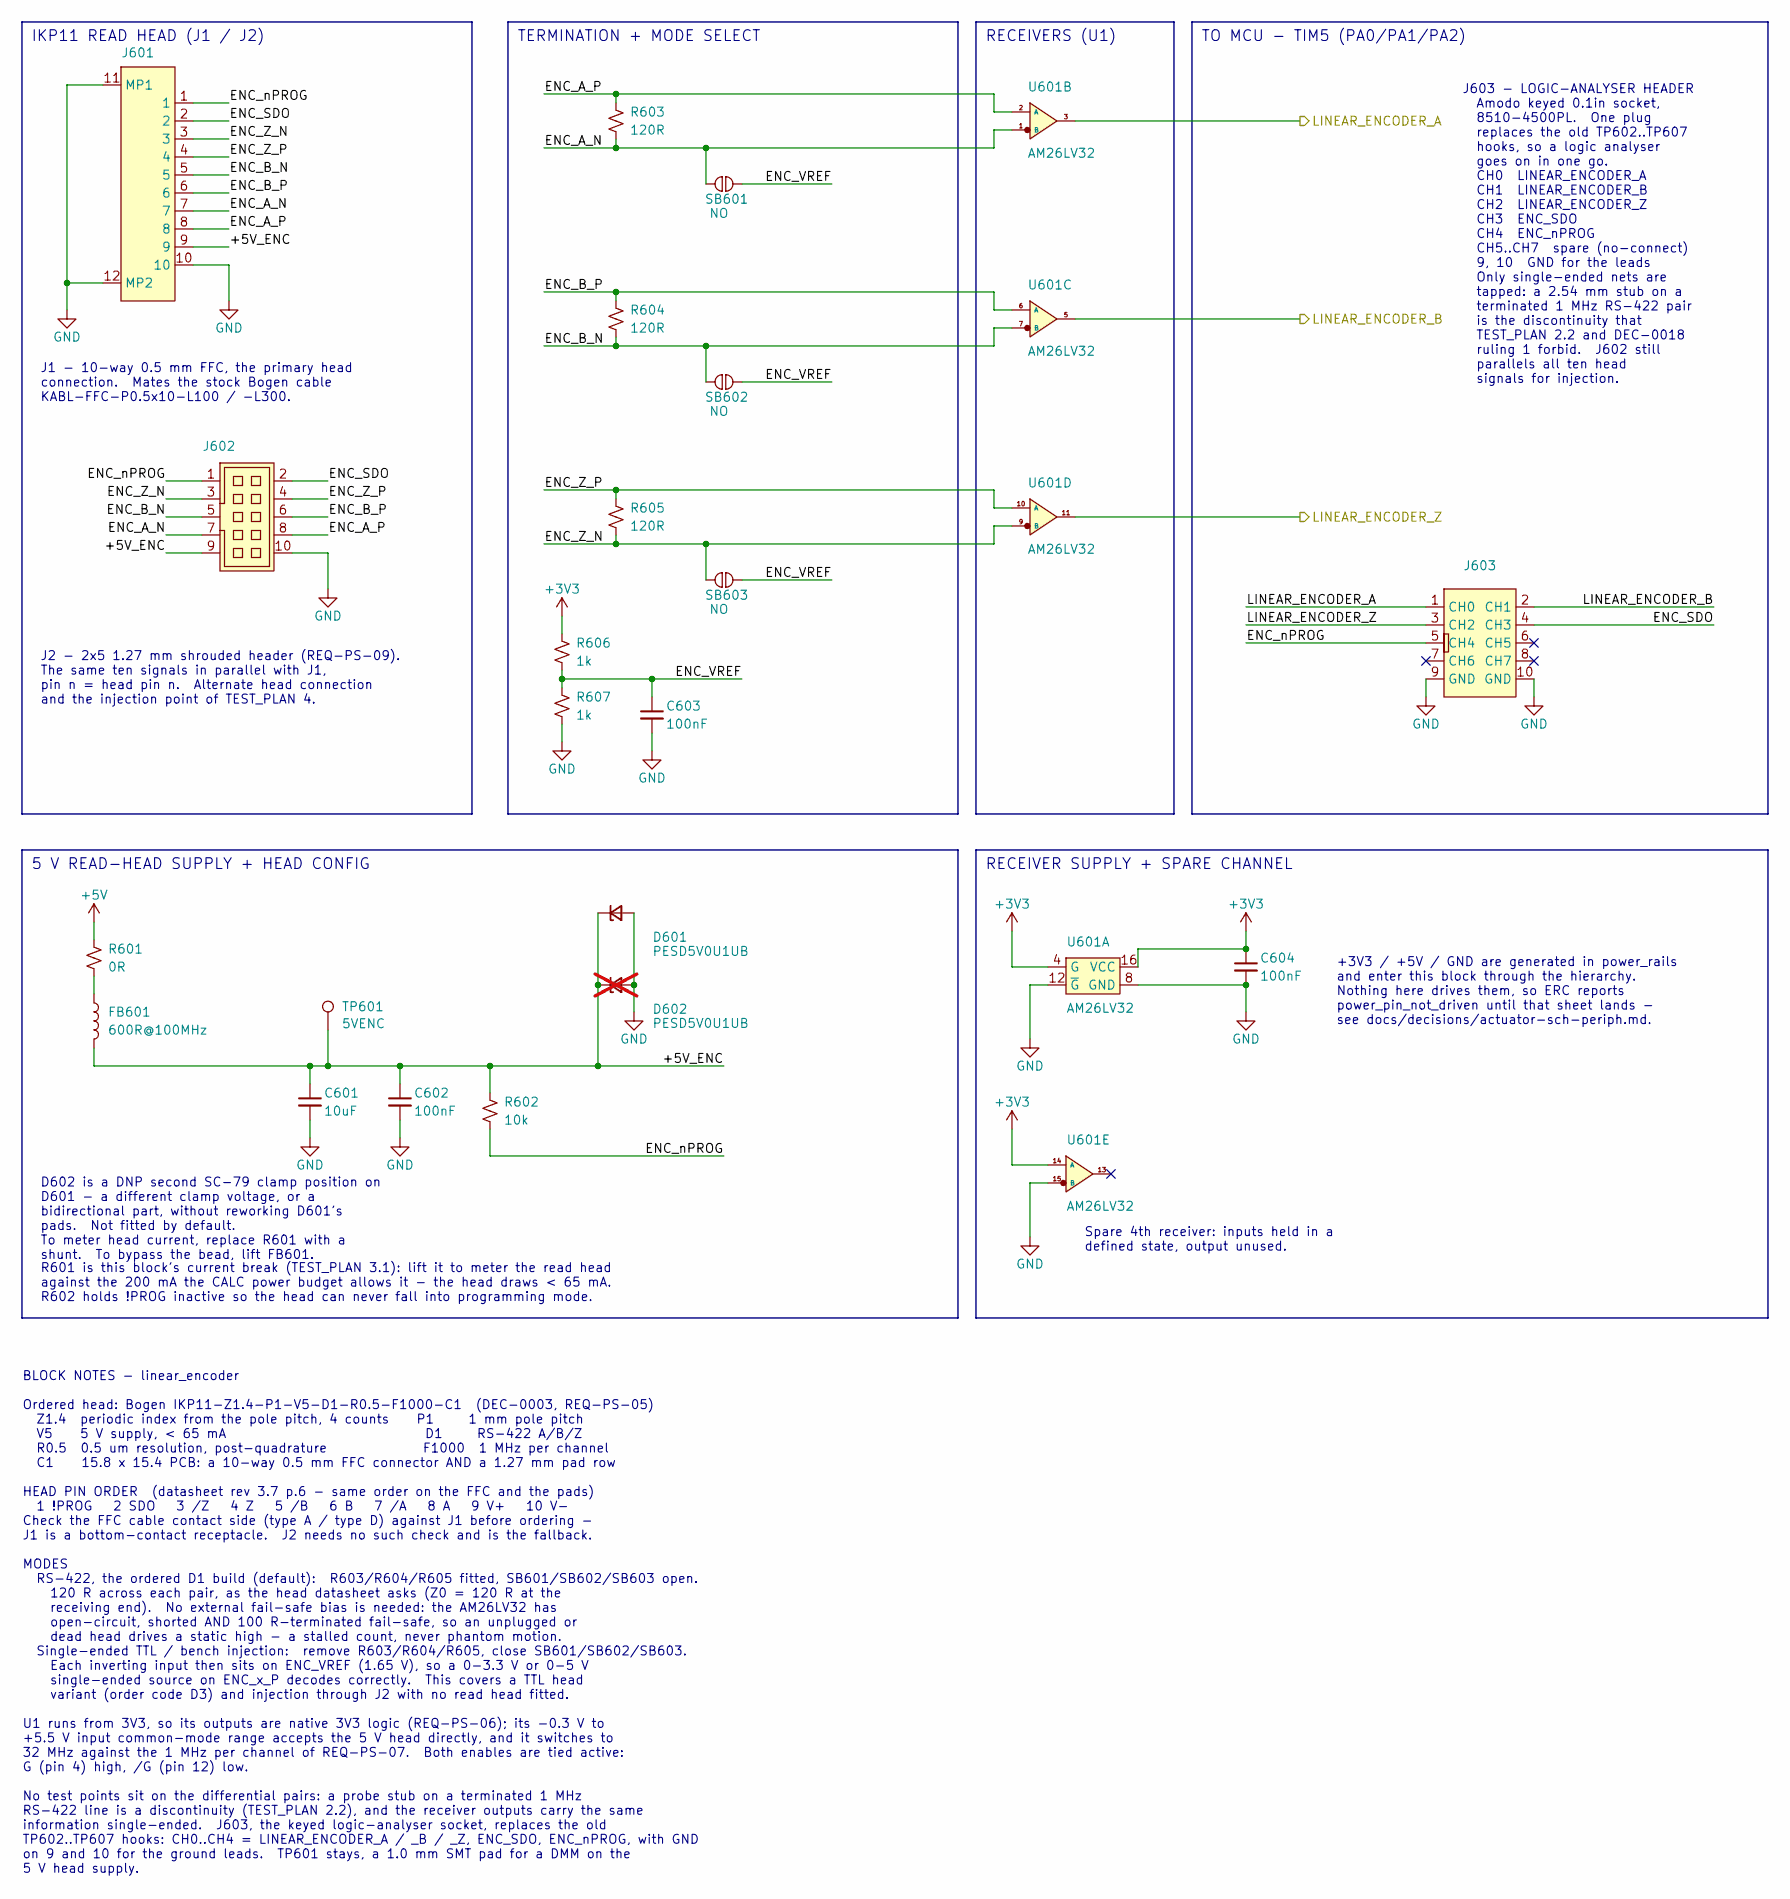
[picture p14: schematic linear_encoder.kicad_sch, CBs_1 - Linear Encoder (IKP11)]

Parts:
C601: 10uF; C_0805_2012Metric; mpn GRM21BR61E106MA73L
C602, C603, C604: 100nF; C_0603_1608Metric; mpn C0603C104M5RACAUTO
D601: PESD5V0U1UB; SC-79 (SOD523); mpn PESD5V0U1UB\,115
D602: PESD5V0U1UB; SC-79 (SOD523); mpn PESD5V0U1UB\,115; not fitted
FB601: 600R@100MHz; R_0603_1608Metric; mpn BLM18HE601SN1D
J601: FH12-10S-0.5SH(55); mpn FH12-10S-0.5SH(55); jlcpn C506791
J602: FTSH-105-01-L-DV-K-TR; mpn FTSH-105-01-L-DV-K-TR
J603: 8510-4500PL; 8510-4500PL_LOGIC_TEST; mpn 8510-4500PL
R601: 0R; R_0603_1608Metric; mpn RC0603FR-070RL
R602: 10k; R_0603_1608Metric; mpn ERJ-3EKF1002V
R603, R604, R605: 120R; R_0603_1608Metric; mpn ERJ-3EKF1200V
R606, R607: 1k; R_0603_1608Metric; mpn CR0603AFX-1001ELF
SB601, SB602, SB603: NO; SOLDER_JUMPER_NO
TP601: 5VENC; TestPoint_Pad_D1.0mm
U601: AM26LV32; SOIC-16-N; mpn AM26LV32CDR

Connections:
+3V3: C604.1, R606.1, U601.4 (G), U601.14 (A), U601.16 (VCC); also elsewhere on the board
+5V: R601.1; also elsewhere on the board
/linear_encoder/+5V_ENC: C601.1, C602.1, D601.1 (K), D602.1 (K), FB601.2, J601.9, J602.9, R602.1, TP601.1
/linear_encoder/ENC_A_N: J601.7, J602.7, R603.2, SB601.1, U601.1 (B)
/linear_encoder/ENC_A_P: J601.8, J602.8, R603.1, U601.2 (A)
/linear_encoder/ENC_B_N: J601.5, J602.5, R604.2, SB602.1, U601.7 (B)
/linear_encoder/ENC_B_P: J601.6, J602.6, R604.1, U601.6 (A)
/linear_encoder/ENC_SDO: J601.2, J602.2, J603.4 (CH3)
/linear_encoder/ENC_VREF: C603.1, R606.2, R607.1, SB601.2, SB602.2, SB603.2
/linear_encoder/ENC_Z_N: J601.3, J602.3, R605.2, SB603.1, U601.9 (B)
/linear_encoder/ENC_Z_P: J601.4, J602.4, R605.1, U601.10 (A)
/linear_encoder/ENC_nPROG: J601.1, J602.1, J603.5 (CH4), R602.2
/linear_encoder/LINEAR_ENCODER_A: J603.1 (CH0), U601.3; also elsewhere on the board
/linear_encoder/LINEAR_ENCODER_B: J603.2 (CH1), U601.5; also elsewhere on the board
/linear_encoder/LINEAR_ENCODER_Z: J603.3 (CH2), U601.11; also elsewhere on the board
GND: C601.2, C602.2, C603.2, C604.2, D601.2 (A), D602.2 (A), J601.10, J601.11 (MP1), J601.12 (MP2), J602.10, J603.9 (GND), J603.10 (GND), R607.2, U601.8 (GND), U601.12 (~G), U601.15 (B); also elsewhere on the board
unnamed: FB601.1, R601.2

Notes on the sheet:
Spare 4th receiver: inputs held in a defined state, output unused.
TO MCU - TIM5 (PA0/PA1/PA2)
J1 - 10-way 0.5 mm FFC, the primary head connection. Mates the stock Bogen cable KABL-FFC-P0.5x10-L100 / -L300.
J603 - LOGIC-ANALYSER HEADER Amodo keyed 0.1in socket, 8510-4500PL. One plug replaces the old TP602..TP607 hooks, so a logic analyser goes on in one go. CH0 LINEAR_ENCODER_A CH1 LINEAR_ENCODER_B CH2 LINEAR_ENCODER_Z CH3 ENC_SDO CH4 ENC_nPROG CH5..CH7 spare (no-connect) 9, 10 GND for the leads Only 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
RECEIVERS (U1)
R601 is this block's current break (TEST_PLAN 3.1): lift it to meter the read head against the 200 mA the CALC power budget allows it - the head draws < 65 mA. R602 holds !PROG inactive so the head can never fall into programming mode.
TERMINATION + MODE SELECT
+3V3 / +5V / GND are generated in power_rails and enter this block through the hierarchy. Nothing here drives them, so ERC reports power_pin_not_driven until that sheet lands - see docs/decisions/actuator-sch-periph.md.
RECEIVER SUPPLY + SPARE CHANNEL
BLOCK NOTES - linear_encoder Ordered head: Bogen IKP11-Z1.4-P1-V5-D1-R0.5-F1000-C1 (DEC-0003, REQ-PS-05) Z1.4 periodic index from the pole pitch, 4 counts P1 1 mm pole pitch V5 5 V supply, < 65 mA D1 RS-422 A/B/Z R0.5 0.5 um resolution, post-quadrature F1000 1 MHz per channel C1 15.8 x 15.4 PCB: a 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
5 V READ-HEAD SUPPLY + HEAD CONFIG
D602 is a DNP second SC-79 clamp position on D601 - a different clamp voltage, or a bidirectional part, without reworking D601's pads. Not fitted by default. To meter head current, replace R601 with a shunt. To bypass the bead, lift FB601.
J2 - 2x5 1.27 mm shrouded header (REQ-PS-09). The same ten signals in parallel with J1, pin n = head pin n. Alternate head connection and the injection point of TEST_PLAN 4.
IKP11 READ HEAD (J1 / J2)

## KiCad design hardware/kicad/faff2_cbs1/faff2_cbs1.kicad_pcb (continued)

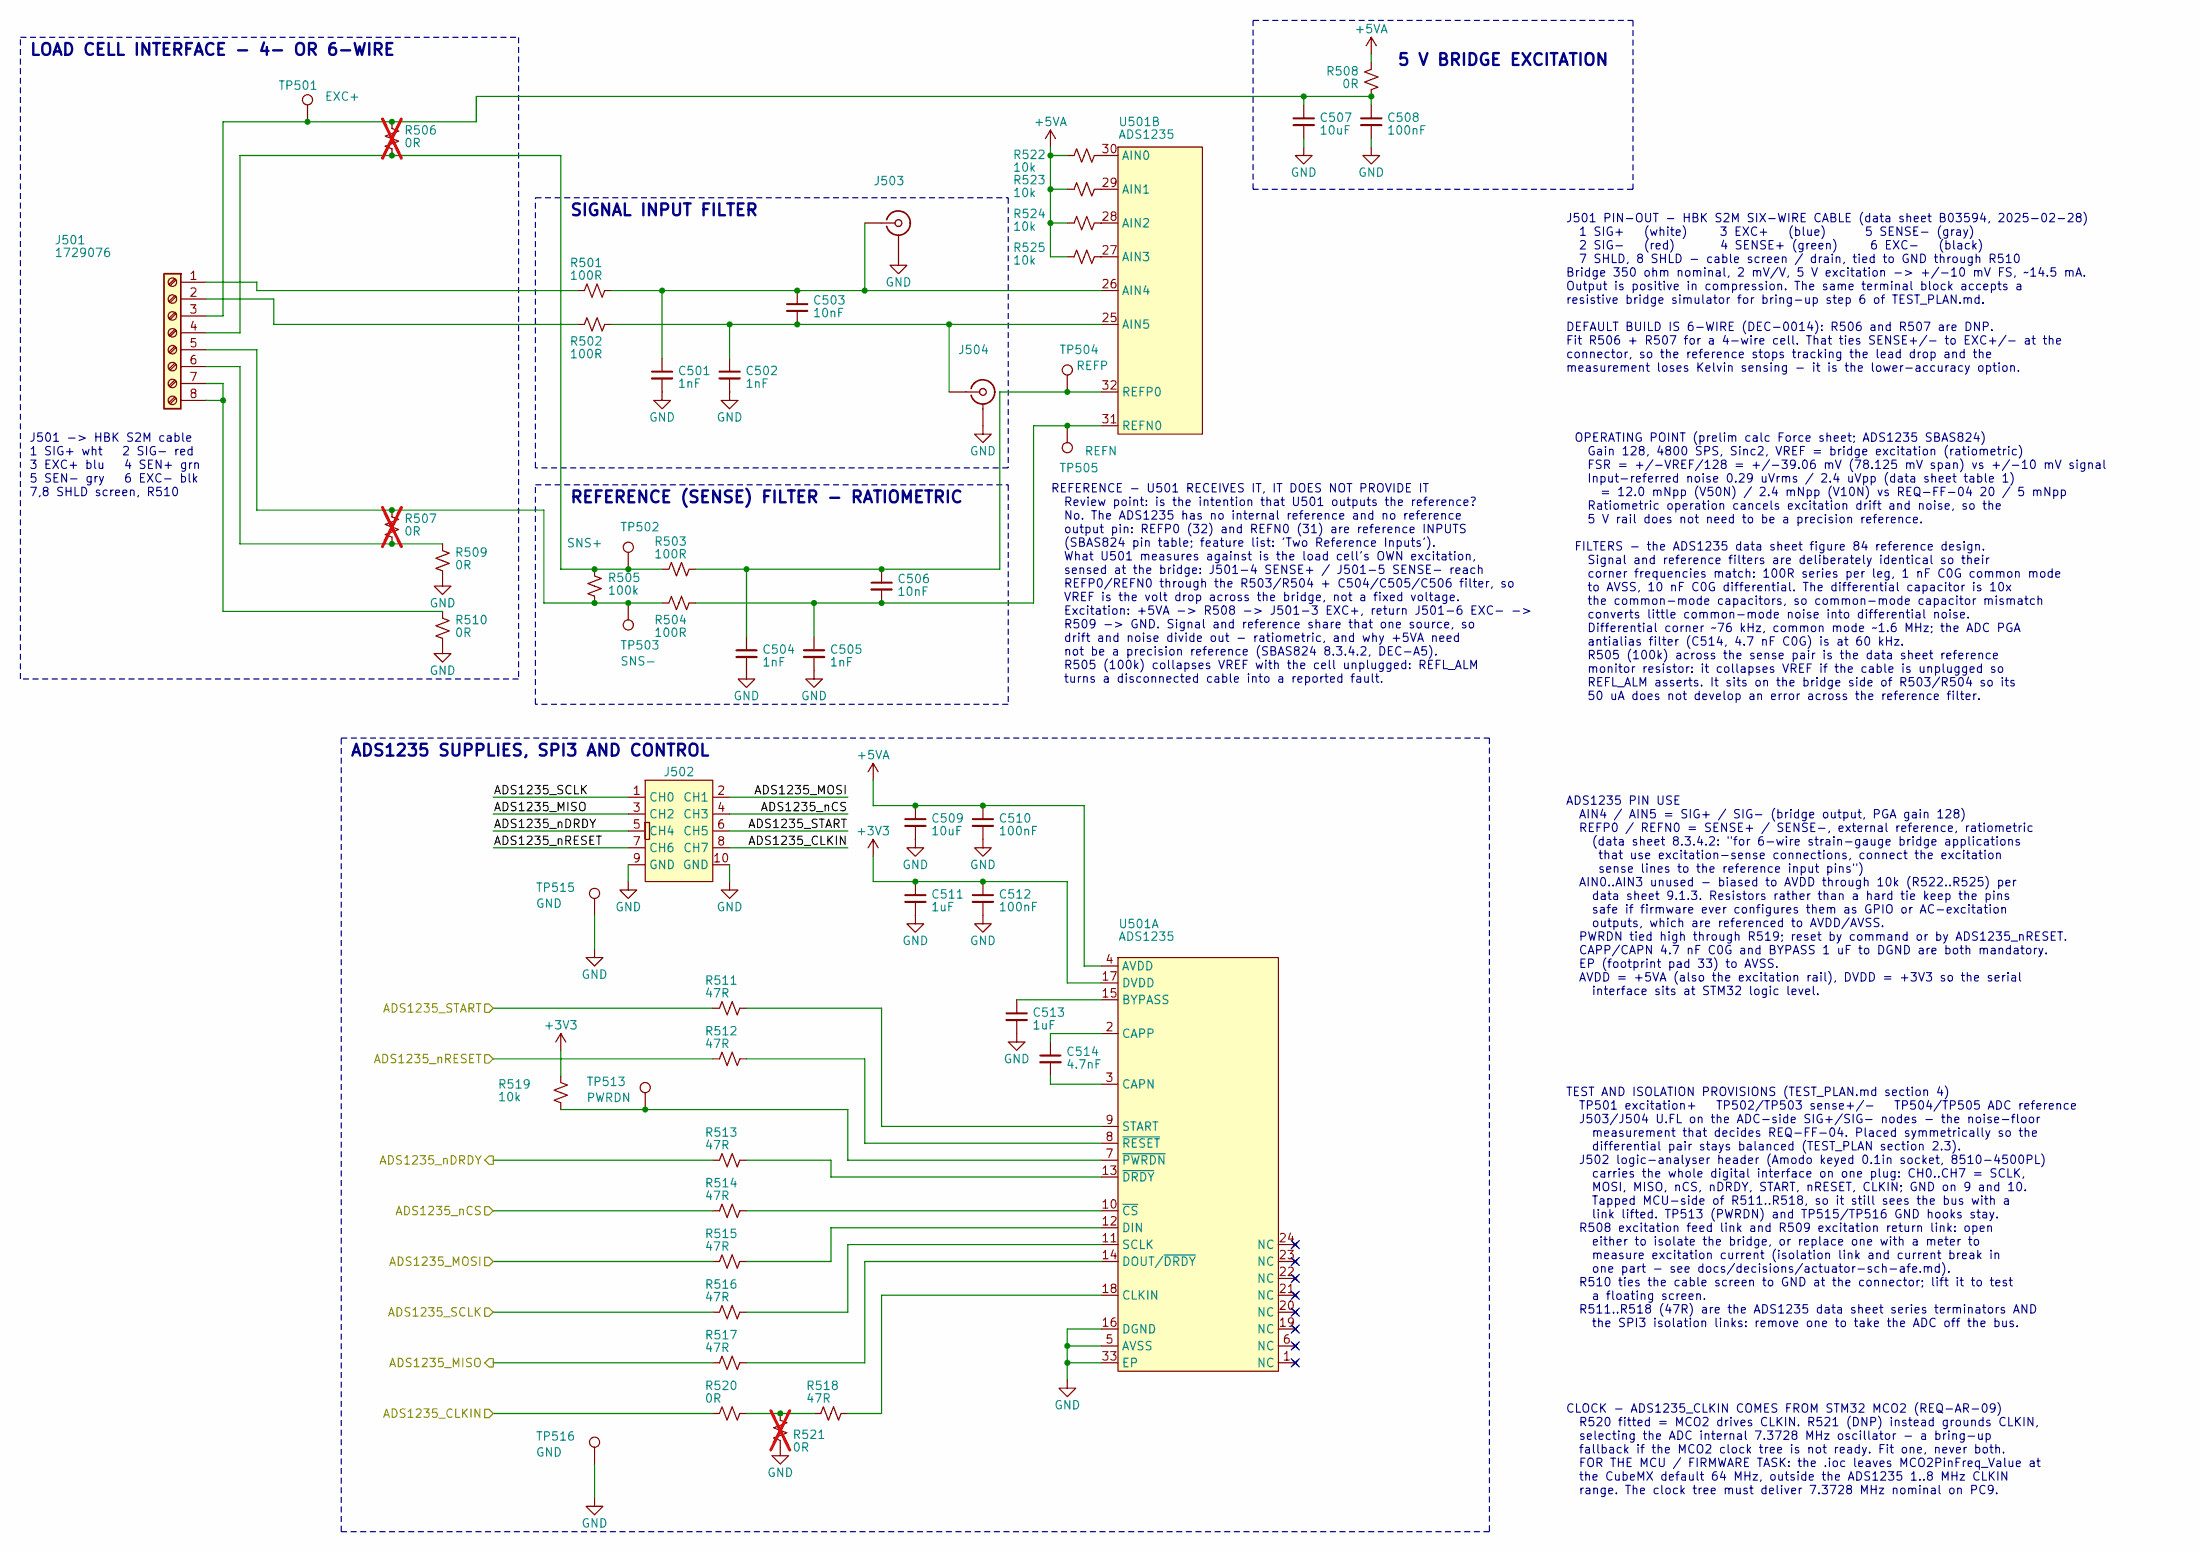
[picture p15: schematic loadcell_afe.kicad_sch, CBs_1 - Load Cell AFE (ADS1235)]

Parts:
C501, C502, C504, C505: 1nF; C_0603_1608Metric; mpn C0603C102F2GEC
C503, C506: 10nF; C_0603_1608Metric; mpn CGA3EAC0G2A103J080AC
C507, C509: 10uF; C_0805_2012Metric; mpn GRM21BR61E106MA73L
C508, C510, C512: 100nF; C_0402_1005Metric; mpn 04025C104KAT2A
C511, C513: 1uF; C_0603_1608Metric; mpn CL10B105KO8NNNC
C514: 4.7nF; C_0805_2012Metric; mpn C0805C472J2GEC7210
J501: 1729076; mpn 1729076
J502: 8510-4500PL; 8510-4500PL_LOGIC_TEST; mpn 8510-4500PL
J503, J504: CONUFL001-SMD; mpn CONUFL001-SMD-T
R501, R502, R503, R504: 100R; R_0603_1608Metric; mpn ERA3AEB101V
R505: 100k; R_0603_1608Metric; mpn ERJ-3EKF1003V
R506, R507, R521: 0R; R_0603_1608Metric; mpn RC0603FR-070RL; not fitted
R508, R509, R510, R520: 0R; R_0603_1608Metric; mpn RC0603FR-070RL
R511, R512, R513, R514, R515, R516, R517, R518: 47R; R_0603_1608Metric; mpn ERJ-3EKF47R0V
R519, R522, R523, R524, R525: 10k; R_0603_1608Metric; mpn ERJ-3EKF1002V
TP501: EXC+; KeystoneMiniatureTestLoop; mpn 5002
TP502: SNS+; TestPoint_Pad_D1.0mm
TP503: SNS-; TestPoint_Pad_D1.0mm
TP504: REFP; TestPoint_Pad_D1.0mm
TP505: REFN; TestPoint_Pad_D1.0mm
TP513: PWRDN; KeystoneMiniatureTestLoop; mpn 5002
TP515, TP516: GND; KeystoneMiniatureTestLoop; mpn 5002
U501: ADS1235; VQFN RHB 32 5x5 mm 0.5 pitch; mpn ADS1235IRHBT

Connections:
+3V3: C511.1, C512.1, R519.1, U501.17 (DVDD); also elsewhere on the board
+5VA: C509.1, C510.1, R508.1, R522.1, R523.1, R524.1, R525.1, U501.4 (AVDD); also elsewhere on the board
/loadcell_afe/ADS1235_CLKIN: J502.8 (CH7), R520.1; also elsewhere on the board
/loadcell_afe/ADS1235_MISO: J502.3 (CH2), R517.1; also elsewhere on the board
/loadcell_afe/ADS1235_MOSI: J502.2 (CH1), R515.1; also elsewhere on the board
/loadcell_afe/ADS1235_SCLK: J502.1 (CH0), R516.1; also elsewhere on the board
/loadcell_afe/ADS1235_START: J502.6 (CH5), R511.1; also elsewhere on the board
/loadcell_afe/ADS1235_nCS: J502.4 (CH3), R514.1; also elsewhere on the board
/loadcell_afe/ADS1235_nDRDY: J502.5 (CH4), R513.1; also elsewhere on the board
/loadcell_afe/ADS1235_nRESET: J502.7 (CH6), R512.1; also elsewhere on the board
GND: C501.2, C502.2, C504.2, C505.2, C507.2, C508.2, C509.2, C510.2, C511.2, C512.2, C513.2, J502.9 (GND), J502.10 (GND), J503.2 (Ext), J503.3 (Ext), J504.2 (Ext), J504.3 (Ext), R509.2, R510.2, R521.2, TP515.1, TP516.1, U501.5 (AVSS), U501.16 (DGND), U501.33 (EP); also elsewhere on the board
unnamed: C507.1, C508.1, J501.3, R506.1, R508.2, TP501.1
unnamed: J501.1, R501.1
unnamed: J501.2, R502.1
unnamed: J501.4, R503.1, R505.1, R506.2, TP502.1
unnamed: J501.5, R504.1, R505.2, R507.1, TP503.1
unnamed: J501.6, R507.2, R509.1
unnamed: J501.7, J501.8, R510.1
unnamed: C501.1, C503.1, J503.1 (In), R501.2, U501.26 (AIN4)
unnamed: C502.1, C503.2, J504.1 (In), R502.2, U501.25 (AIN5)
unnamed: R518.1, R520.2, R521.1
unnamed: C513.1, U501.15 (BYPASS)
unnamed: C514.2, U501.3 (CAPN)
unnamed: C514.1, U501.2 (CAPP)
unnamed: R518.2, U501.18 (CLKIN)
unnamed: R515.2, U501.12 (DIN)
unnamed: R517.2, U501.14 (DOUT/~DRDY)
unnamed: R516.2, U501.11 (SCLK)
unnamed: R511.2, U501.9 (START)
unnamed: R514.2, U501.10 (~CS)
unnamed: R513.2, U501.13 (~DRDY)
unnamed: R519.2, TP513.1, U501.7 (~PWRDN)
unnamed: R512.2, U501.8 (~RESET)
unnamed: R522.2, U501.30 (AIN0)
unnamed: R523.2, U501.29 (AIN1)
unnamed: R524.2, U501.28 (AIN2)
unnamed: R525.2, U501.27 (AIN3)
unnamed: C505.1, C506.2, R504.2, TP505.1, U501.31 (REFN0)
unnamed: C504.1, C506.1, R503.2, TP504.1, U501.32 (REFP0)

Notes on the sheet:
CLOCK - ADS1235_CLKIN COMES FROM STM32 MCO2 (REQ-AR-09) R520 fitted = MCO2 drives CLKIN. R521 (DNP) instead grounds CLKIN, selecting the ADC internal 7.3728 MHz oscillator - a bring-up fallback if the MCO2 clock tree is not ready. Fit one, never both. FOR THE MCU / FIRMWARE TASK: the .ioc leaves MC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
REFERENCE - U501 RECEIVES IT, IT DOES NOT PROVIDE IT Review point: is the intention that U501 outputs the reference? No. The ADS1235 has no internal reference and no reference output pin: REFP0 (32) and REFN0 (31) are reference INPUTS (SBAS824 pin table; feature list: 'Two Reference Inputs'). What 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
LOAD CELL INTERFACE - 4- OR 6-WIRE
OPERATING POINT (prelim calc Force sheet; ADS1235 SBAS824) Gain 128, 4800 SPS, Sinc2, VREF = bridge excitation (ratiometric) FSR = +/-VREF/128 = +/-39.06 mV (78.125 mV span) vs +/-10 mV signal Input-referred noise 0.29 uVrms / 2.4 uVpp (data sheet table 1) = 12.0 mNpp (V50N) / 2.4 mNpp (V10N) vs RE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
J501 -> HBK S2M cable 1 SIG+ wht 2 SIG- red 3 EXC+ blu 4 SEN+ grn 5 SEN- gry 6 EXC- blk 7,8 SHLD screen, R510
SIGNAL INPUT FILTER
ADS1235 SUPPLIES, SPI3 AND CONTROL
REFERENCE (SENSE) FILTER - RATIOMETRIC
ADS1235 PIN USE AIN4 / AIN5 = SIG+ / SIG- (bridge output, PGA gain 128) REFP0 / REFN0 = SENSE+ / SENSE-, external reference, ratiometric (data sheet 8.3.4.2: "for 6-wire strain-gauge bridge applications that use excitation-sense connections, connect the excitation sense lines to the reference input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
J501 PIN-OUT - HBK S2M SIX-WIRE CABLE (data sheet B03594, 2025-02-28) 1 SIG+ (white) 3 EXC+ (blue) 5 SENSE- (gray) 2 SIG- (red) 4 SENSE+ (green) 6 EXC- (black) 7 SHLD, 8 SHLD - cable screen / drain, tied to GND through R510 Bridge 350 ohm nominal, 2 mV/V, 5 V excitation -> +/-10 mV FS, ~14.5 mA. Ou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
TEST AND ISOLATION PROVISIONS (TEST_PLAN.md section 4) TP501 excitation+ TP502/TP503 sense+/- TP504/TP505 ADC reference J503/J504 U.FL on the ADC-side SIG+/SIG- nodes - the noise-floor measurement that decides REQ-FF-04. Placed symmetrically so the differential pair stays balanced (TEST_PLAN sectio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
5 V BRIDGE EXCITATION

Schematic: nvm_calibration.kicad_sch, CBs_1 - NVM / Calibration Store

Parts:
C801: 100nF; C_0603_1608Metric; mpn C0603C104M5RACAUTO
R801, R802: 0R; R_0603_1608Metric; mpn RC0603FR-070RL
R803, R804: 4.7k; R_0603_1608Metric; mpn ERJ-3EKF4701V
R805: 10k; R_0603_1608Metric; mpn ERJ-3EKF1002V
SB801, SB802: NC; SOLDER_JUMPER_NC
SB803: NO; SOLDER_JUMPER_NO
TP801: SCL; KeystoneMiniatureTestLoop; mpn 5002
TP802: SDA; KeystoneMiniatureTestLoop; mpn 5002
TP803: WP; TestPoint_Pad_D1.0mm
TP804, TP805: GND; KeystoneMiniatureTestLoop; mpn 5002
U801: 24FC16T-I/OT; SOT23-5 - TI; mpn 24FC16T-I/OT

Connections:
+3V3: C801.1, R801.1, R802.1, SB803.2, U801.4 (VCC); also elsewhere on the board
/mcu/EEPROM_SCL: R803.2, SB801.1, TP801.1; also elsewhere on the board
/mcu/EEPROM_SDA: R804.2, SB802.1, TP802.1; also elsewhere on the board
GND: C801.2, R805.2, TP804.1, TP805.1, U801.2 (VSS); also elsewhere on the board
unnamed: R801.2, R803.1
unnamed: R802.2, R804.1
unnamed: SB801.2, U801.1 (SCL)
unnamed: SB802.2, U801.3 (SDA)
unnamed: R805.1, SB803.1, TP803.1, U801.5 (WP)

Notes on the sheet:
R801/R802 are the removable links of TEST_PLAN 4: lift either to drop its pull-up. SB801/SB802 are cut to take the EEPROM off I2C1 while the bus stays pulled up - this block owns that break, so mcu must not duplicate it. The SDA pull-up crosses the SCL run, no junction.
BLOCK NOTES - nvm_calibration U1 = Microchip 24FC16T-I/OT, 16 kbit (2048 x 8) I2C EEPROM in SOT-23-5. Pin map verified against the datasheet package drawing (DS20001703R p.1): 1 SCL 2 VSS 3 SDA 4 VCC 5 WP. 1.7-5.5 V and 1 MHz capable, so it keeps up with I2C1 at either 400 kHz or Fast-mode Plus, an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
I2C1 BUS, PULL-UPS, ISOLATION
GND hooks beside TP801/TP802 for the scope or analyser clips.
EEPROM, DECOUPLING, WRITE PROTECT
GROUND HOOKS
+3V3 and GND are generated in power_rails and enter this block through the hierarchy; nothing here drives them, so ERC reports power_pin_not_driven until that sheet lands. See docs/decisions/actuator-sch-periph.md.
WP is ACTIVE HIGH. R805 holds it low, so the part is writable and firmware can store calibration at any time; solder SB803 to lock the device permanently. TP3 lets a jig drive WP either way. This resolves OQ-06 - no MCU pin is spent on write protect.

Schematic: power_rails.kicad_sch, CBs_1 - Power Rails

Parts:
C301, C302, C315, C316: 10uF; C_1206_3216Metric; Voltage 50V; mpn GRT31CR61H106ME01L
C303, C317: 220nF; C_0805_2012Metric; mpn HMK212B7224KG-T
C304, C318: 1uF; C_0603_1608Metric; mpn CL10B105KO8NNNC
C305, C308, C311, C314, C319, C322, C324: 100nF; C_0603_1608Metric; mpn C0603C104M5RACAUTO
C306, C307, C320, C321: 22uF; C_1206_3216Metric; Voltage 16V; mpn CL31A226MOCLNNC
C309, C312: 10uF; C_0603_1608Metric; mpn CL10B105KO8NNNC
C310, C313, C323: 10uF; C_0603_1608Metric; mpn ZRB18AR61A106ME01L
D303: SM0805URC; LED 0805 SM0805; mpn SM0805URC
FB301: 600R@100MHz; R_0603_1608Metric; mpn BLM18HE601SN1D
J301: PH1-06-UA; Adam_Tech_PH1-06-UA; mpn PH1-06-UA
L301: 15uH; L_Bourns_SRR1210; mpn SRR1210-150M
L302: 6.8uH; IND_ASPI-0630HI; mpn ASPI-0630HI-6R8M
R301, R308, R313: 100k; R_0603_1608Metric; mpn ERJ-3EKF1003V
R302, R309: 8.2k; R_0603_1608Metric; mpn ERJ-3EKF8201V
R303: 64k9; R_0603_1608Metric; tolerance 0.1%; mpn ERA-3AEB6492V
R304: 12k7; R_0603_1608Metric; Tolerance 0.1%; mpn ERA-3AEB1272V
R305, R306, R307, R312: 0R; R_0603_1608Metric; mpn RC0603FR-070RL
R310: 100k; R_0603_1608Metric; tolerance 0.1%; mpn ERA-3VEB1003V
R311: 43k; R_0603_1608Metric; mpn CRCW060343K0FKEA
R314: 330R; R_0603_1608Metric; mpn ERJ-3EKF3300V
R315, R316, R317, R318: 1k; R_0603_1608Metric; mpn CR0603AFX-1001ELF
TP302: +6V0; TestPoint_Dual_D1.5mm_H1.0mm
TP303: +5V; TestPoint_Dual_D1.5mm_H1.0mm
TP304: +5VA; TestPoint_Dual_D1.5mm_H1.0mm
TP306: +3V3; TestPoint_Dual_D1.5mm_H1.0mm
TP307: +3V3A; TestPoint_Dual_D1.5mm_H1.0mm
TP308: PGOOD; KeystoneMiniatureTestLoop; mpn 5002
TP309, TP310, TP311, TP312: GND; KeystoneMiniatureTestLoop; mpn 5002
U301, U304: LMR33630; PowerPAD SOIC-8 HSOIC (8); mpn LMR33630
U302, U303: ADPL42005; LFCSP-8 - 3x3mm body - 0.5mm pitch - 2.5x1.8mm EP; mpn ADPL42005ACPZ-5.0-R7

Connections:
+3V3: FB301.1, J301.2, R312.2, R313.1, R314.1, TP306.1; also elsewhere on the board
+3V3A: C323.1, C324.1, FB301.2, J301.3, TP307.1; also elsewhere on the board
+5V: J301.1, R306.2, TP303.1; also elsewhere on the board
+5VA: R307.2, TP304.1; also elsewhere on the board
/power_entry_24v/V24_LOGIC: C301.1, C302.1, C303.1, C315.1, C316.1, C317.1, R301.1, R308.1, U301.2 (VIN), U304.2 (VIN); also elsewhere on the board
/power_rails/+6V0: C309.1, C312.1, R305.2, TP302.1, U302.5 (EN), U302.8 (VIN), U303.5 (EN), U303.8 (VIN)
/power_rails/RAIL_PGOOD: D303.2, R313.2, R315.2, R316.2, R317.2, R318.2, TP308.1
GND: C301.2, C302.2, C303.2, C304.2, C306.2, C307.2, C308.2, C309.2, C310.2, C311.2, C312.2, C313.2, C314.2, C315.2, C316.2, C317.2, C318.2, C320.2, C321.2, C322.2, C323.2, C324.2, J301.4, J301.5, J301.6, R302.2, R304.2, R309.2, R311.2, TP302.2, TP303.2, TP304.2, TP306.2, TP307.2, TP309.1, TP310.1, TP311.1, TP312.1, U301.1 (PGND), U301.TP (GND), U302.3 (GND), U302.6 (GND), U302.9 (EP), U303.3 (GND), U303.6 (GND), U303.9 (EP), U304.1 (PGND), U304.TP (GND); also elsewhere on the board
unnamed: C306.1, C307.1, C308.1, L301.2, R303.1, R305.1
unnamed: C320.1, C321.1, C322.1, L302.2, R310.1, R312.1
unnamed: D303.1, R314.2
unnamed: C305.1, U301.7 (BOOT)
unnamed: R301.2, R302.1, U301.3 (EN)
unnamed: R303.2, R304.1, U301.5 (FB)
unnamed: R315.1, U301.4 (PG)
unnamed: C305.2, L301.1, U301.8 (SW)
unnamed: C304.1, U301.6 (VCC)
unnamed: R317.1, U302.7 (PG)
unnamed: C310.1, C311.1, R306.1, U302.1 (VOUT), U302.2 (SENSE)
unnamed: R318.1, U303.7 (PG)
unnamed: C313.1, C314.1, R307.1, U303.1 (VOUT), U303.2 (SENSE)
unnamed: C319.1, U304.7 (BOOT)
unnamed: R308.2, R309.1, U304.3 (EN)
unnamed: R310.2, R311.1, U304.5 (FB)
unnamed: R316.1, U304.4 (PG)
unnamed: C319.2, L302.1, U304.8 (SW)
unnamed: C318.1, U304.6 (VCC)

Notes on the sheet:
6.0 V, not 5.0 V: it is the ADPL42005's own characterised VIN = VOUT + 1 V point, so the LDOs meet their noise and PSRR numbers on +5VA, which carries REQ-FF-04. R303/R304 are sized so the worst-case floor clears 6.0 V, not just the nominal: 6.009 / 6.110 / 6.212 V. Was 5.5 V while the TPS7A20's 6.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
D. ANALOG 3V3, RAIL POWER-GOOD, AND THE RAIL PROBE HEADER
POWER SOURCE DECLARATIONS One PWR_FLAG per rail produced here, at the regulator that makes it, on the load side of that rail's 0R link. No other sheet may add one for these nets.
RAIL PROBE HEADER (TEST_PLAN 4) One header to check every logic rail with a DMM during bring-up steps 2 and 3 of TEST_PLAN 5. It only observes: the rails, their isolation links and their current breaks are the rest of this sheet. 1 +5V 2 +3V3 3 +3V3A 4 GND 5 GND 6 GND +24V IS DELIBERATELY NOT ON TH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
A. PRE-REGULATOR V24_LOGIC -> 6.0 V (LMR33630, 400 kHz)
EN is tied to each LDO input - the datasheet's own automatic-startup connection - so the 5 V rails follow the pre-regulator with no sequencing logic. SENSE ties to VOUT at the regulator, not past the 0R link, so lifting the link cannot open the loop. PG is unused: no-connect, not tied to RAIL_PGOOD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
C. 3V3 REGULATOR V24_LOGIC -> 3.3 V (LMR33630, 400 kHz)
BLOCK: power_rails - rail set and topology; answers OQ-02 and OQ-07 RAILS +6V0 LMR33630 buck from V24_LOGIC. Pre-regulator only, local to this sheet. +5V ADPL42005 LDO from +6V0. IKP11 read head (<65 mA plus RS-422 drive) and spare. +5VA ADPL42005 LDO from +6V0. ADS1235 / ADS1120 AVDD and the AFE 5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
PER RAIL (docs/TEST_PLAN.md 3.1) one 0R link that is BOTH the isolation link and the current-measurement break, a test point downstream of it, on a dual pad so a scope ground clips beside the probe. No test point sits on a feedback node: R305 +6V0, R306 +5V, R307 +5VA, R312 +3V3, FB301 +3V3A. Per-C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
B. POST-REGULATED 5 V RAILS (ADPL42005: +5V digital, +5VA analog)
FB301 is the +3V3A isolation link and current break: lift it and the ADC digital supplies are cut loose.

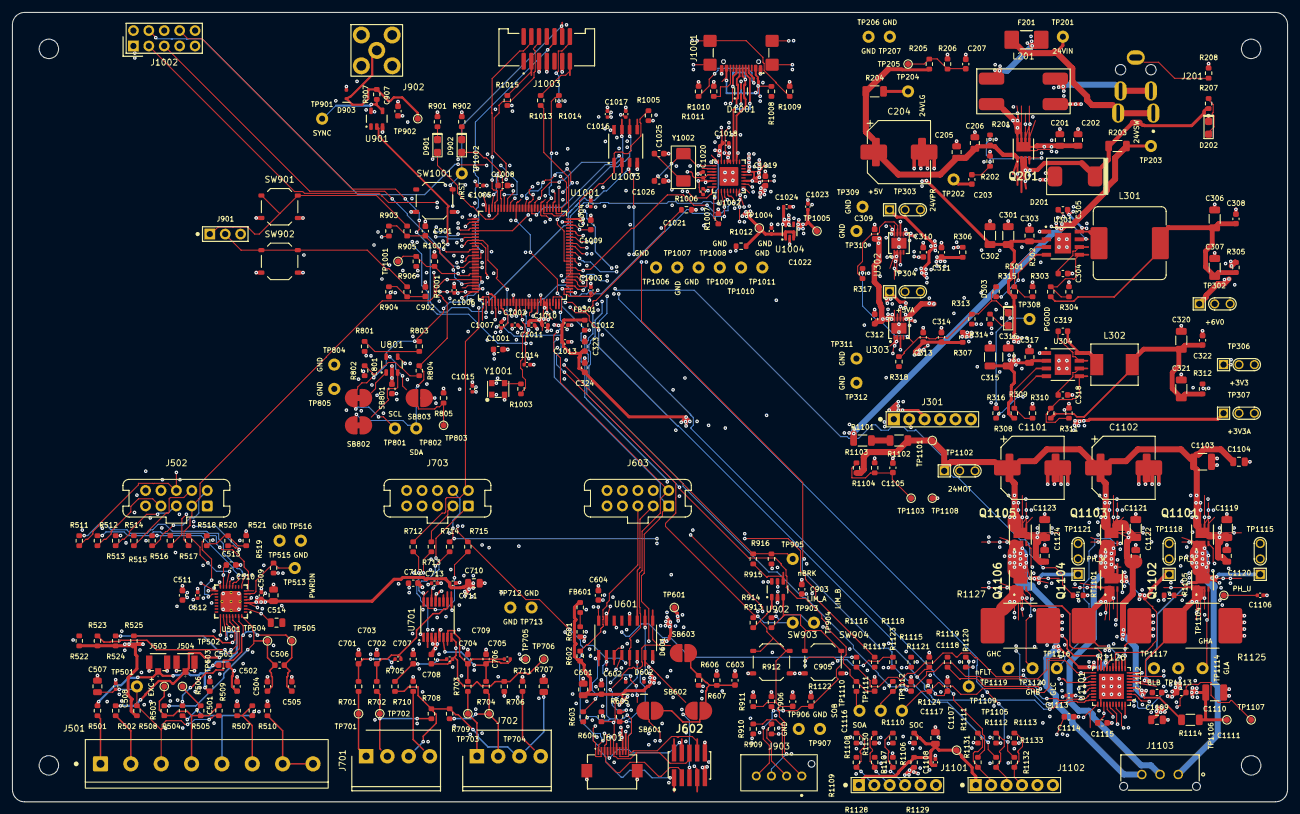
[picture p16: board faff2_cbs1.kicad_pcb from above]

Board: 6 copper layers, 210.0 x 130.0 mm, 412 parts (0 on the bottom side), 240 nets.

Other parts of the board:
H1, H2, H3, H4: MountingHole_3.2mm_M3_NO-PAD_NPTH

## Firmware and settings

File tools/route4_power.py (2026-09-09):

#!/usr/bin/env python3
"""Routing step 4 -- the power distribution.

Two passes.

**Trunks** (`TRUNKS`) are the deliberate high-current and source-chain paths,
routed in the order the current actually flows and on the component layer, at
widths chosen from the IPC-2221 table in `docs/decisions/actuator-pcb-setup.md`
S3 rather than from the net class alone -- G3 says power is deliberate traces,
G1c says widen locally.  The 24 V bus, the motor bus, both switcher SW nodes
and both switcher output nodes are here, and so is every source-chain
capacitor step 2 deferred: the flow reads source pad -> cap pad -> next pin,
in line, no via inside a switching loop.

**Distribution** then completes each rail with the maze router, joining what
the trunks left to the 49 feed vias step 2 planted.  Rails carry a mild F.Cu
cost bias so the long hauls settle on B.Cu, under the traffic, which is what
the feed vias were put there for.

Per-via current budget is 1.0 A (setup S3).  `VIA_BUDGET` records the design
current for every rail that changes layer, and `tools/route_check.py --power`
proves the counts.
"""
import os
import sys

import pcbnew

sys.path.insert(0, os.path.dirname(os.path.abspath(__file__)))
import route_lib as R  # noqa: E402

# --------------------------------------------------------------------------
# Design currents.  25 W peak at 24 V = 1.04 A for the whole board (REQ-EL-03);
# the motor branch is sized on the 3 A peak the setup file assumed for the
# phases (1.23 A static, prelim calc).  n = ceil(I / 1.0 A), minimum 2 on any
# rail that changes layer.
# --------------------------------------------------------------------------
VIA_BUDGET = {
    "/power_entry_24v/V24_IN": 3.0,
    "Net-(F201-Pad2)": 3.0,
    "Net-(Q201-D)": 3.0,
    "/power_entry_24v/V24_PROT": 3.0,
    "/power_entry_24v/V0_IN": 3.0,
    "/power_entry_24v/+24V_SW": 3.0,
    "Net-(R1101-Pad2)": 3.0,
    "/motor_drive/V24_MOT": 3.0,
    "/motor_drive/MOTOR_U": 3.0,
    "/motor_drive/MOTOR_V": 3.0,
    "/motor_drive/MOTOR_W": 3.0,
    # The low-side source nets carry the leg's full current from the FET
    # source into its shunt, the same 3 A the phase node sees.  They are named
    # after the FET rather than the phase, which is why they were missed.
    "Net-(Q1102-S_3)": 3.0,
    "Net-(Q1104-S_3)": 3.0,
    "Net-(Q1106-S_3)": 3.0,
    "/power_entry_24v/V24_LOGIC": 0.3,
    "Net-(U301-SW)": 0.7,
    "Net-(C306-Pad1)": 0.7,
    "/power_rails/+6V0": 0.6,
    "Net-(U302-SENSE)": 0.3,
    "Net-(U303-SENSE)": 0.3,
    "+5V": 0.3,
    "+5VA": 0.3,
    "Net-(U304-SW)": 1.5,
    "Net-(C320-Pad1)": 1.5,
    "+3V3": 1.5,
    "+3V3A": 0.2,
    "/mcu/+3V3_USB": 0.3,
    "/mcu/+1V8_USB": 0.2,
    "/linear_encoder/+5V_ENC": 0.3,
    "/motor_drive/VENC": 0.3,
    "/motor_drive/VM_DRV": 0.1,
}

# (net, [(ref, pad), ...], width mm)
TRUNKS = [
    # -- 24 V entry: jack -> fuse -> common-mode choke -> reverse-protect FET
    ("/power_entry_24v/V24_IN", [("J201", "1"), ("J201", "2")], 1.0),
    ("/power_entry_24v/V24_IN", [("J201", "2"), ("F201", "1")], 1.0),
    ("/power_entry_24v/V24_IN", [("F201", "1"), ("TP201", "1")], 0.5),
    ("Net-(F201-Pad2)", [("F201", "2"), ("L201", "1")], 1.0, (R.F, R.B)),
    ("Net-(Q201-D)", [("L201", "2"), ("Q201", "5")], 1.0),
    ("/power_entry_24v/V0_IN", [("J201", "3"), ("J201", "4")], 1.0),
    ("/power_entry_24v/V0_IN", [("J201", "4"), ("L201", "4")], 1.0, (R.F, R.B)),
    # the drain-side reservoir pair sits in line on the drain node
    ("Net-(Q201-D)", [("Q201", "5"), ("C201", "1"), ("C202", "1")], 0.8),
    # -- protected 24 V: TVS first (closest to the source), then the bulk
    ("/power_entry_24v/V24_PROT", [("Q201", "1"), ("D201", "2")], 1.0),
    ("/power_entry_24v/V24_PROT", [("Q201", "1"), ("C206", "1"), ("C205", "1")], 0.8),
    ("/power_entry_24v/V24_PROT", [("C205", "1"), ("C204", "1")], 1.0),
    ("/power_entry_24v/V24_PROT", [("C204", "1"), ("R204", "1")], 1.0),
    ("/power_entry_24v/V24_PROT", [("Q201", "1"), ("R203", "1")], 1.0),
    # -- the switched 24 V branch and the motor-bus current break
    ("/power_entry_24v/+24V_SW", [("R203", "2"), ("TP203", "1")], 0.5),
    # 45 mm across the whole regulator block: on B.Cu, under the traffic.
    # On F.Cu this trace slices the power_rails block in half diagonally and
    # walls off every local link in it.
    ("/power_entry_24v/+24V_SW", [("R203", "2"), ("R1101", "1")], 1.0,
     (R.B,)),
    ("Net-(R1101-Pad2)", [("R1101", "2"), ("R1102", "1")], 1.0),
    # -- motor bus: break -> DC-link store -> across the high-side drains
    ("/motor_drive/V24_MOT", [("R1102", "2"), ("TP1101", "1")], 1.0),
    ("/motor_drive/V24_MOT", [("TP1101", "1"), ("TP1102", "1")], 1.0),
    ("/motor_drive/V24_MOT", [("TP1102", "1"), ("C1101", "1")], 1.0),
    ("/motor_drive/V24_MOT", [("C1101", "1"), ("C1102", "1")], 1.0),
    ("/motor_drive/V24_MOT", [("C1102", "1"), ("C1103", "1")], 1.0),
    ("/motor_drive/V24_MOT", [("C1103", "1"), ("C1104", "1")], 1.0),
    # each leg is fed from the store directly above it
    ("/motor_drive/V24_MOT", [("C1101", "1"), ("Q1105", "5_6_7_8")], 1.0),
    ("/motor_drive/V24_MOT", [("C1102", "1"), ("Q1103", "5_6_7_8")], 1.0),
    ("/motor_drive/V24_MOT", [("C1103", "1"), ("Q1101", "5_6_7_8")], 1.0),
    # per-leg bypass, in line off its own drain -- the commutation loop
    ("/motor_drive/V24_MOT", [("Q1105", "5_6_7_8"), ("C1123", "1")], 0.8),
    ("/motor_drive/V24_MOT", [("C1123", "1"), ("C1124", "1")], 0.8),
    ("/motor_drive/V24_MOT", [("Q1103", "5_6_7_8"), ("C1121", "1")], 0.8),
    ("/motor_drive/V24_MOT", [("C1121", "1"), ("C1122", "1")], 0.8),
    ("/motor_drive/V24_MOT", [("Q1101", "5_6_7_8"), ("C1119", "1")], 0.8),
    ("/motor_drive/V24_MOT", [("C1119", "1"), ("C1120", "1")], 0.8),
    # driver supply take-off and its own current break
    # driver supply take-off: leg-A drain is the nearest V24_MOT copper to
    # the break resistor, and it carries only the DRV8323's own ~30 mA
    ("/motor_drive/V24_MOT", [("Q1101", "5_6_7_8"), ("R1114", "1")], 0.6,
     (R.F, R.B)),
    ("/motor_drive/VM_DRV", [("R1114", "2"), ("TP1106", "1")], 0.5),
    # the DRV's own VM pin is a 0.25 mm pad on a 0.5 mm pitch row: the bus
    # narrows for the last 8 mm, which is what it carries (~30 mA)
    ("/motor_drive/V24_MOT", [("R1114", "1"), ("U1101", "5")], 0.25,
     (R.F, R.B)),
    # -- buck 1: VIN caps came in step 2; SW node, boot, output, sense
    ("Net-(U301-SW)", [("U301", "8"), ("L301", "1")], 0.65),
    ("Net-(U301-SW)", [("L301", "1"), ("C305", "2")], 0.40),
    ("Net-(U301-BOOT)", [("C305", "1"), ("U301", "7")], 0.30),
    ("Net-(C306-Pad1)", [("L301", "2"), ("C306", "1")], 0.80),
    ("Net-(C306-Pad1)", [("C306", "1"), ("C308", "1")], 0.80),
    ("Net-(C306-Pad1)", [("C306", "1"), ("C307", "1")], 0.80),
    ("Net-(C306-Pad1)", [("C307", "1"), ("R305", "1")], 0.80),
    ("Net-(C306-Pad1)", [("C308", "1"), ("R303", "1")], 0.25),
    ("/power_rails/+6V0", [("R305", "2"), ("TP302", "1")], 0.50, (R.F, R.B)),
    # both LDOs take VIN on two adjacent pins -- tie them at the package
    ("/power_rails/+6V0", [("U302", "8"), ("U302", "5")], 0.30),
    ("/power_rails/+6V0", [("U303", "8"), ("U303", "5")], 0.30),
    # -- buck 2
    ("Net-(U304-SW)", [("U304", "8"), ("L302", "1")], 0.65),
    ("Net-(U304-SW)", [("L302", "1"), ("C319", "2")], 0.40),
    ("Net-(U304-BOOT)", [("C319", "1"), ("U304", "7")], 0.30),
    ("Net-(C320-Pad1)", [("L302", "2"), ("C320", "1")], 0.80),
    ("Net-(C320-Pad1)", [("C320", "1"), ("C322", "1")], 0.80),
    ("Net-(C320-Pad1)", [("C320", "1"), ("C321", "1")], 0.80),
    ("Net-(C320-Pad1)", [("C321", "1"), ("R312", "1")], 0.80),
    ("Net-(C320-Pad1)", [("C322", "1"), ("R310", "1")], 0.25),
    ("+3V3", [("R312", "2"), ("TP306", "1")], 0.50),
    # -- the two LDOs: output pin -> its own caps -> the current-break link
    ("Net-(U302-SENSE)", [("U302", "1"), ("U302", "2")], 0.30),
    ("Net-(U302-SENSE)", [("U302", "2"), ("C310", "1")], 0.50),
    ("Net-(U302-SENSE)", [("C310", "1"), ("C311", "1")], 0.50),
    ("Net-(U302-SENSE)", [("C311", "1"), ("R306", "1")], 0.50),
    ("+5V", [("R306", "2"), ("TP303", "1")], 0.50),
    ("Net-(U303-SENSE)", [("U303", "1"), ("U303", "2")], 0.30),
    ("Net-(U303-SENSE)", [("U303", "2"), ("C313", "1")], 0.50),
    ("Net-(U303-SENSE)", [("C313", "1"), ("C314", "1")], 0.50),
    ("Net-(U303-SENSE)", [("C314", "1"), ("R307", "1")], 0.50),
    ("+5VA", [("R307", "2"), ("TP304", "1")], 0.50),
    # -- +3V3A: the ferrite's output caps sit in line at the MCU (P1-05)
    ("+3V3A", [("FB301", "2"), ("C323", "1")], 0.50),
    ("+3V3A", [("C323", "1"), ("C324", "1")], 0.50),
    # the PHY's four +3V3_USB pins on the east row, tied along the package
    ("/mcu/+3V3_USB", [("U1002", "11"), ("U1002", "14")], 0.24),
    # -- +5V_ENC current break (the 70 mm haul to R601 is the distribution
    # pass's job, on B.Cu, not a trunk)
    ("Net-(FB601-Pad1)", [("R601", "2"), ("FB601", "1")], 0.50),
]

# Rails completed by the maze router after the trunks, in this order.
# (net, width, F.Cu cost bias -- higher pushes the long hauls onto B.Cu)
RAILS = [
    ("/power_entry_24v/V24_IN", 1.00, 0.0),
    ("Net-(F201-Pad2)", 1.00, 0.0),
    ("/power_entry_24v/V0_IN", 1.00, 0.0),
    ("Net-(Q201-D)", 0.80, 0.0),
    ("/power_entry_24v/V24_PROT", 0.50, 0.0),
    ("/power_entry_24v/+24V_SW", 0.50, 0.0),
    ("/motor_drive/V24_MOT", 1.00, 0.0),
    ("/motor_drive/VM_DRV", 0.50, 0.2),
    ("/power_entry_24v/V24_LOGIC", 0.50, 0.35),
    ("Net-(C306-Pad1)", 0.50, 0.0),
    ("/power_rails/+6V0", 0.50, 0.35),
    ("Net-(U302-SENSE)", 0.50, 0.0),
    ("Net-(U303-SENSE)", 0.50, 0.0),
    ("+5V", 0.50, 0.35),
    ("+5VA", 0.50, 0.35),
    ("Net-(C320-Pad1)", 0.50, 0.0),
    ("+3V3", 0.50, 0.35),
    ("+3V3A", 0.50, 0.20),
    ("Net-(FB601-Pad1)", 0.50, 0.0),
    ("/linear_encoder/+5V_ENC", 0.50, 0.30),
    ("/motor_drive/VENC", 0.50, 0.30),
    ("/mcu/+3V3_USB", 0.50, 0.30),
    ("/mcu/+1V8_USB", 0.40, 0.30),
]

# Local power-block sense / enable / power-good nets: thin, and kept away from
# the SW nodes by routing them after the rails are down.
SENSE = ["Net-(U301-EN)", "Net-(U301-FB)", "Net-(U301-PG)",
         "Net-(U304-EN)", "Net-(U304-FB)", "Net-(U304-PG)",
         "Net-(U302-PG)", "Net-(U303-PG)", "/power_rails/RAIL_PGOOD",
         "Net-(D303-Pad1)", "Net-(Q201-G)", "Net-(D202-Pad1)",
         "Net-(J201-SH)", "Net-(U1002-RBIAS)"]


def grp(board, ref, num):
    out = []
    for f in board.GetFootprints():
        if f.GetReference() != ref:
            continue
        for p in f.Pads():
            if p.GetNumber() == num and R.pad_copper_layers(p):
                out.append((ref, p))
    if not out:
        raise KeyError(f"{ref}.{num}")
    return out


def grp_min_dim(g):
    bs = [R.pad_bbox(p) for _r, p in g]
    bb = (min(b[0] for b in bs), min(b[1] for b in bs),
          max(b[2] for b in bs), max(b[3] for b in bs))
    return min(bb[2] - bb[0], bb[3] - bb[1])


def main():
    board = R.load()
    obst = R.Obstacles(board)
    print(f"   {obst.reserve_pin_escapes(board)} fine-pitch pin escape lanes held")
    maze = R.Maze(obst)

    print("== fan-out: fine-pitch pins first, so nothing can cap a lane")
    R.escape_pass(board, obst)

    print("\n== trunks (component layer unless noted, current-flow order)")
    fails = []
    for entry in TRUNKS:
        net, seq, w = entry[0], entry[1], entry[2]
        lay = entry[3] if len(entry) > 3 else (R.F,)
        for a, b in zip(seq, seq[1:]):
            ln, width, nv, direct = R.link(board, obst, maze, net, a, b, w,
                                           layers=lay, margin=14, via_cost=45)
            if ln is None:
                fails.append((net, a, b, w))
                print(f"   FAIL {net:<28} {a[0]}.{a[1]} -> {b[0]}.{b[1]} "
                      f"@{w}")
                continue
            print(f"   {net:<28} {a[0]+'.'+a[1]:<14} -> "
                  f"{b[0]+'.'+b[1]:<14} {width:5.2f} mm  {ln:6.2f} mm"
                  f"  (direct {direct:5.2f}, vias {nv})")

    print("\n== rail distribution (feed vias are the anchors)")
    for net, w, bias in RAILS:
        f = R.connect_net(board, obst, maze, net, width=w, via_cost=55,
                          margin=18, layer_bias={R.F: bias})
        n = len(R.pad_nodes(board, net))
        print(f"   {net:<30} {n:3d} nodes @ {w:4.2f} mm"
              + ("  UNROUTED " + ",".join(sorted(set(f))) if f else ""))

    print("\n== power-block sense / enable / power-good")
    for net in SENSE:
        w = R.net_width(net)
        f = R.connect_net(board, obst, maze, net, width=max(w, 0.20),
                          via_cost=60, margin=20)
        print(f"   {net:<30}" + ("  UNROUTED " + ",".join(sorted(set(f)))
                                 if f else "  ok"))

    # Reload from disk before repairing.  A board object that has taken many
    # hundreds of Add()s behaves differently from the same board read back --
    # five nets that connect_net refuses in-run route first time from a fresh
    # read - so the repair pass always works on a re-read board.
    R.refill(board)
    R.save(board)
    board = R.load()

    print("\n== repair pass (fresh read, fresh obstacle model)")
    todo = [n for n in ([e[0] for e in TRUNKS] + [r[0] for r in RAILS] + SENSE)
            if not R.net_is_whole(board, n)]
    seen, order = set(), []
    for n in todo:
        if n not in seen:
            seen.add(n)
            order.append(n)
    left = R.repair(board, order,
                    widths={r[0]: r[1] for r in RAILS})
    print(f"   retried {len(order)}: {order}")
    if left:
        print(f"   STILL OPEN: {left}")

    if fails:
        print("\nTRUNK FAILURES:", fails)
    R.refill(board)
    R.save(board)
    print("\nunconnected now:", R.unconnected(board))


if __name__ == "__main__":
    main()

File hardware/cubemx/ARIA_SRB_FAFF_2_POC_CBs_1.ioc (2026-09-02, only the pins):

Mcu.UserName=STM32H723VETx
PA0.GPIO_Label=LINEAR_ENCODER_A
PA0.Signal=S_TIM5_CH1
PA1.GPIO_Label=LINEAR_ENCODER_B
PA1.Signal=S_TIM5_CH2
PA11.GPIO_Label=LED_2
PA11.Signal=GPIO_Output
PA12.GPIO_Label=LED_1
PA12.Signal=GPIO_Output
PA13(JTMS/SWDIO).Signal=DEBUG_JTMS-SWDIO
PA14(JTCK/SWCLK).Signal=DEBUG_JTCK-SWCLK
PA15(JTDI).GPIO_Label=ADS1235_nCS
PA15(JTDI).Signal=SPI3_NSS
PA2.GPIO_Label=LINEAR_ENCODER_Z
PA2.Signal=S_TIM5_CH3
PA3.Signal=USB_OTG_HS_ULPI_D0
PA4.GPIO_Label=MOTOR_FETTEMP
PA4.Signal=ADCx_INP18
PA5.Signal=USB_OTG_HS_ULPI_CK
PA6.GPIO_Label=MOTOR_I_A
PA6.Signal=ADCx_INP3
PA7.GPIO_Label=MOTOR_I_C
PA7.Signal=ADCx_INP7
PA9.GPIO_Label=CONFIG_SPI_SCK
PA9.Signal=SPI2_SCK
PB0.Signal=USB_OTG_HS_ULPI_D1
PB1.Signal=USB_OTG_HS_ULPI_D2
PB10.Signal=USB_OTG_HS_ULPI_D3
PB11.Signal=USB_OTG_HS_ULPI_D4
PB12.Signal=USB_OTG_HS_ULPI_D5
PB13.Signal=USB_OTG_HS_ULPI_D6
PB14.GPIO_Label=CONFIG_SPI_MISO
PB14.Signal=SPI2_MISO
PB15.GPIO_Label=CONFIG_SPI_MOSI
PB15.Signal=SPI2_MOSI
PB2.GPIO_Label=QSPI_P1_CLK
PB2.Signal=OCTOSPIM_P1_CLK
PB3(JTDO/TRACESWO).Signal=DEBUG_JTDO-SWO
PB5.Signal=USB_OTG_HS_ULPI_D7
PB6.GPIO_Label=QSPI_P1_nCS
PB6.Signal=OCTOSPIM_P1_NCS
PB8.GPIO_Label=EEPROM_SCL
PB8.Signal=I2C1_SCL
PB9.GPIO_Label=EEPROM_SDA
PB9.Signal=I2C1_SDA
PC0.Signal=USB_OTG_HS_ULPI_STP
PC1.GPIO_Label=V24_MON
PC1.Signal=ADCx_INP11
PC10.GPIO_Label=ADS1235_SCLK
PC10.Signal=SPI3_SCK
PC11.GPIO_Label=ADS1235_MISO
PC11.Signal=SPI3_MISO
PC12.GPIO_Label=ADS1235_START
PC12.Signal=GPIO_Output
PC2_C.Signal=USB_OTG_HS_ULPI_DIR
PC3_C.Signal=USB_OTG_HS_ULPI_NXT
PC4.GPIO_Label=MOTOR_I_B
PC4.Signal=ADCx_INP4
PC5.GPIO_Label=VBUS_MON
PC5.Signal=ADCx_INP8
PC6.GPIO_Label=MOTOR_ENCODER_A
PC6.Signal=S_TIM3_CH1
PC7.GPIO_Label=MOTOR_ENCODER_B
PC7.Signal=S_TIM3_CH2
PC8.GPIO_Label=MOTOR_ENCODER_I
PC8.Signal=S_TIM3_CH3
PC9.GPIO_Label=ADS1235_CLKIN
PC9.Signal=RCC_MCO_2
PD0.GPIO_Label=ADS1235_nRESET
PD0.Signal=GPIO_Output
PD1.GPIO_Label=ADS1235_nDRDY
PD1.Signal=GPXTI1
PD10.GPIO_Label=DRV8323_EN
PD10.Signal=GPIO_Output
PD11.GPIO_Label=QSPI_P1_IO0
PD11.Signal=OCTOSPIM_P1_IO0
PD12.GPIO_Label=QSPI_P1_IO1
PD12.Signal=OCTOSPIM_P1_IO1
PD13.GPIO_Label=QSPI_P1_IO3
PD13.Signal=OCTOSPIM_P1_IO3
PD14.GPIO_Label=HALL2
PD14.Signal=GPIO_Input
PD15.GPIO_Label=HALL3
PD15.Signal=GPIO_Input
PD2.GPIO_Label=LIM_A
PD2.Signal=GPXTI2
PD3.GPIO_Label=ADS1120_nCS
PD3.Signal=GPIO_Output
PD4.GPIO_Label=LIM_B
PD4.Signal=GPXTI4
PD5.GPIO_Label=DRV8323_CAL
PD5.Signal=GPIO_Output
PD6.GPIO_Label=ADS1235_MOSI
PD6.Signal=SPI3_MOSI
PD7.GPIO_Label=DRV8323_nCS
PD7.Signal=GPIO_Output
PD8.GPIO_Label=DBG_TX
PD8.Signal=USART3_TX
PD9.GPIO_Label=DBG_RX
PD9.Signal=USART3_RX
PE0.GPIO_Label=BTN_1
PE0.Signal=GPIO_Input
PE1.GPIO_Label=BTN_2
PE1.Signal=GPIO_Input
PE10.GPIO_Label=MOTOR_PWM_BL
PE10.Signal=TIM1_CH2N
PE11.GPIO_Label=MOTOR_PWM_BH
PE11.Signal=S_TIM1_CH2
PE12.GPIO_Label=MOTOR_PWM_CL
PE12.Signal=TIM1_CH3N
PE13.GPIO_Label=MOTOR_PWM_CH
PE13.Signal=S_TIM1_CH3
PE14.GPIO_Label=HALL1
PE14.Signal=GPIO_Input
PE15.GPIO_Label=DRV8323_nFAULT
PE15.Signal=TIM1_BKIN
PE2.GPIO_Label=QSPI_P1_IO2
PE2.Signal=OCTOSPIM_P1_IO2
PE4.GPIO_Label=USB3320_nRESET
PE4.Signal=GPIO_Output
PE5.GPIO_Label=SYNC_TRIG
PE5.Signal=S_TIM15_CH1
PE6.GPIO_Label=LIMIT_nBRK
PE6.Signal=TIM1_BKIN2
PE8.GPIO_Label=MOTOR_PWM_AL
PE8.Signal=TIM1_CH1N
PE9.GPIO_Label=MOTOR_PWM_AH
PE9.Signal=S_TIM1_CH1
PH0-OSC_IN.Signal=RCC_OSC_IN

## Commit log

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2026-09-03 mcu, test_debug: draw the MCU + USB + QSPI RAM and debug blocks
    Fills the two block sheets this task owns. Nothing else in the KiCad
    project is touched, and no MCU pin is re-assigned - the .ioc stays the
    authority (DEC-0013) and was traced against the block diagram with no
    conflict found.
    mcu.kicad_sch
    - STM32H723VET6 across all six units, with DS13313 supply treatment:
    100nF per VDD pin plus a 4u7 bulk, 2x2u2 on VCAP (Table 14),
    2x100nF + 2x1uF on VDDA/VREF+, 100nF on NRST (Figure 18).
    - Boot and reset: 10k BOOT0 pull-down fitted, 1k pull-up DNP for DFU,
    reset button, hook test point, MCU_nRESET out to test_debug.
    - 24 MHz MEMS oscillator feeding both the STM32 HSE (exter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
    [mcu.kicad_sch, test_debug.kicad_sch]
2026-09-03 power: draw the 24 V entry and rail blocks
    power_entry_24v: KPJX-4S 24 V in with doubled contacts, 2 A time-lag fuse,
    common-mode choke on both lines, P-channel reverse-polarity series FET with a
    gate-source soft start, 5 kW TVS and bulk downstream of it, and the V24_MON
    divider into PC1. Two independent 0R branch links so the motor stage can be
    left unpowered while the rest of the board is brought up (TEST_PLAN 3.3).
    power_rails: answers OQ-02 and OQ-07. LMR33630 buck to a 5.5 V pre-regulator
    feeding two TPS7A20 LDOs (+5V digital for the IKP11 read head, +5VA analog for
    the ADCs and the AFE excitation chain), a second LMR33630 buck to +3V3, and a
    ferrite-isolated +3V3A for the ADC digital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
    [power_entry_24v.kicad_sch, power_rails.kicad_sch]
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2026-09-03 periph: design record for the three peripheral blocks
    Records every judgement call behind linear_encoder, nvm_calibration and
    ui_io, the root sheet pins the integration pass must add, the residual
    ERC classes and why they are hierarchy-context only, the one new Amodo
    library part and the datasheets fetched to justify each part choice.
    Resolves OQ-06 (EEPROM write protect: tied off with a link and a test
    point, no MCU pin); leaves OQ-05 open as a firmware/silkscreen matter.
    Claude-Session: https://claude.ai/code/session_01BewsoRxMKiykAUhQw3HtBp
    [ui_io.kicad_sch]
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2026-09-03 periph: move the FH12-10S part into project-local libraries
    AmodoKiCadLib is read-only (captain rule), so the one new part this
    block needed lives in the project instead:
    hardware/kicad/faff2_cbs1/faff2_periph.kicad_sym symbol
    hardware/kicad/faff2_cbs1/faff2.pretty/ footprint
    with sym-lib-table and fp-lib-table entries resolved through
    ${KIPRJMOD}. faff2.pretty is shared with motor_drive; distinct
    .kicad_mod filenames do not collide.
    linear_encoder.kicad_sch now references faff2_periph:FH12-10S-0.5SH(55)
    with footprint faff2:FH12-10S-0.5SH(55); no stale Amodo reference to the
    part remains. The earlier edits to Amodo_Connectors.kicad_sym and
    Amodo.pretty were reverted wi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
    [linear_encoder.kicad_sch]
2026-09-03 loadcell_afe: ADS1235 bridge AFE, 5 V ratiometric excitation, 4/6-wire S2M
    Draws the load cell analog front end per REQ-FF-01..13 and REQ-AR-08/09,
    at the prelim-calc operating point (gain 128, 4800 SPS, Sinc2, FSR
    +/-39.06 mV against a +/-10 mV bridge output, 2.4 uVpp input noise).
    - J501 (Phoenix 1729076, 8-way 5 mm screw terminal) takes the HBK S2M
    six-wire cable plus its screen. R506/R507 are DNP 0R links that tie
    SENSE+/- to EXC+/- for a 4-wire cell; default build is 6-wire per
    DEC-0014.
    - Excitation is the +5VA analog rail through R508, with R509 in the
    bridge return: either link isolates the bridge or takes a meter.
    - Signal and reference filters are the ADS1235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
    [loadcell_afe.kicad_sch]
2026-09-03 temp_sense: two 3-wire Pt1000 channels on one ADS1120; AFE symbol goes local
    Draws temp_sense and completes the analog front end. Reasoning, the answer to
    OQ-04 and the root-sheet interface list are in docs/decisions/actuator-sch-afe.md.
    temp_sense (REQ-EL-07, REQ-AR-10):
    - OQ-04 answered: RTD, not NTC. Pt1000, 3-wire, class A. The ADS1120's two
    matched IDACs exist to excite an RTD ratiometrically and cancel lead
    resistance; a class-A RTD is interchangeable to +/-(0.15 + 0.002|t|) degC
    with no per-part calibration, which an NTC would need to reach 1 degC.
    Pt1000 over Pt100 because every error term here is an error in ohms, and at
    3.85 ohm/degC each costs ten times less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
    [loadcell_afe.kicad_sch, temp_sense.kicad_sch]
2026-09-03 afe: place 180-rotated field text where KiCad actually renders it
    KiCad mirrors field justification for a 180-degree-rotated symbol, so a
    `justify left` field grows leftward from its anchor. That put the TP702/TP704
    references over the 2-wire link values and the TP501/TP503/TP505 references
    where the field offsets did not expect them. These sheets now set `justify
    right` on 180-rotated symbols so every field grows rightward like all the
    others, and the two probe test points moved clear of the link resistors.
    The bundled overlap checker does not model that flip, and separately reflects
    the body of any mirrored or rotated symbol about its origin, so it now reports
    ten findings on these two sh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
    [loadcell_afe.kicad_sch, temp_sense.kicad_sch]
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2026-09-03 motor_drive: correct the designators quoted in the sheet notes and the record
    Designators are allocated in placement order, so the numbers written into the
    on-sheet notes and docs/decisions/actuator-sch-motor.md by hand were wrong: the
    shunts are R1125-R1127 not R1301-R1303, the break-path link is R1119, and the
    motor phase connector is J1103. Every designator the record quotes now exists
    on the sheet.
    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
    [motor_drive.kicad_sch]
2026-09-03 integrate: per-sheet power designators, and RAIL_PGOOD stays sheet-local
    Two prerequisites for the root-wiring pass.
    loadcell_afe and temp_sense both annotated their power symbols from
    #PWR001, so the two sets silently merged into one component set at
    netlist time. Renumbered to the sheet ranges AGENTS.md already fixes for
    every other block: #PWR5xx for loadcell_afe, #PWR7xx for temp_sense. No
    other sheet collides, checked across all ten.
    RAIL_PGOOD was a hierarchical label with no consumer anywhere in the
    project: power_rails produces it, and the only thing that would read it
    is the MCU GPIO that OQ-07 has not allocated. A sheet pin on a net with
    one endpoint is an ERC error, so it is dem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
    [loadcell_afe.kicad_sch, power_rails.kicad_sch, temp_sense.kicad_sch]
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2026-09-03 review r1 batch 2: power_rails - LMR51610 pre-regulator, dual TPs, flow fixes
    The captain's second review batch, all six points, on power_rails.
    1 TP301 and TP305 deleted - test coverage off both PSU feedback nodes, and
    that same edit leaves U301's 4-way FB junction a plain 3-way tee
    2 every regulator output gets an Amodo TestPointDual (probe pad + ground
    clip), hung below its rail on a stub so the pads clear the wire they tap
    3 R305/R306/R307/R312 laid horizontal, so each rail runs one way and steps
    down once instead of stepping through its own link
    4 U301 -> LMR51610XFDBVR, the buck ARIA_EITSYS_CBs_1 uses
    5 FB301 laid horizontal, in line on the +3V3 rail
    6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
    [power_rails.kicad_sch]
2026-09-03 review r1: logic-analyser headers, U501 reference note, AFE/encoder fixes
    Answers the captain's round-1 review points on loadcell_afe, linear_encoder,
    temp_sense and nvm_calibration.
    U501 and the reference (R1). The ADS1235 has no internal reference and no
    reference output pin - REFP0/REFN0 are inputs. The reference is the load cell's
    own excitation, sensed at the bridge, which is what makes the measurement
    ratiometric. Documented in a 15-line note beside U501B's reference pins.
    Logic-analyser headers (R2, R5). The Amodo keyed 10-way 0.1in socket
    (8510-4500PL) replaces the per-net hooks:
    J502 loadcell_afe CH0..CH7 = the whole SPI3 interface plus nDRDY, START,
    n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
    [linear_encoder.kicad_sch, loadcell_afe.kicad_sch, nvm_calibration.kicad_sch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]
2026-09-03 review r1: dissolve test_debug into mcu, split the 24 MHz clock, A2 mcu, ui_io flow
    Captain's review, three batches, all landing on mcu.kicad_sch so they ship together.
    test_debug.kicad_sch is deleted. Its three blocks moved onto the sheet they serve:
    H the SWD + USART3 debug header, J the rail probe header, K the GND hooks - all on
    mcu, renumbered into the 10xx range (J401->J1003, R401/402->R1013/1014, J402->J1004,
    TP401..406->TP1006..1011, #PWR401..414->#PWR1051..1064). The six SWD/USART3 nets were
    shared only with mcu, so they are sheet-local labels now and their twelve sheet pins
    came off the root. Nine blocks; pages renumber 2..10 and the refdes ranges become a
    fixed table with 4xx ret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
    [faff2_cbs1.kicad_sch, mcu.kicad_sch, test_debug.kicad_sch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]
2026-09-03 review r1 batch 3: motor_drive - bridge decoupling, label flow, R1101/R1102 note
    The captain's motor_drive batch, all four points.
    1 the 24 V feed note said R101/R102 and read as fit-one-or-the-other. The
    refdes were wrong; the parts are genuinely two 0R in series, both fitted
    (D-MOT-14), so the note is rewritten to say that outright and give each
    link its own job
    2 C1101's reference ran into C1102's body at the old 8.89 pitch - the bulk
    column respaced, and TP1103 moved clear of the capacitor value row
    3 eight hierarchical labels had their text lying along their own wire:
    seven took their wire from the left while facing left, and +24V_SW ran
    verticall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
    [motor_drive.kicad_sch]
2026-09-03 review r1 final sweep: power labels, TP silkscreen names, text overlaps
    The captain's design-wide pass, run once the per-sheet batches had landed.
    Presentation only: ERC 0 errors / 0 warnings at severity-all, 404 components,
    251 nets, and every per-net node set identical to the pre-sweep export.
    power labels 92 rail names were hidden on loadcell_afe, motor_drive and
    temp_sense - all 285 power symbols now read, placed to the
    house pattern (GND below the symbol, rail arrows above)
    test points 66 of 83 still carried the library default "TestPoint". All
    83 now name what they measure, from the net they actually
    land on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
    [linear_encoder.kicad_sch, loadcell_afe.kicad_sch, mcu.kicad_sch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]
2026-09-03 review r2 item 1: U301 back to the LMR33630
    The captain overruled the reference-part swap for U301 only. Reverted the buck,
    R304 (16.9k -> 22.1k), L301 (33uH -> 15uH), and the three parts the LMR51610 had
    no pins for: C304 on VCC, the thermal-pad ground, and R315 in the PG leg.
    RAIL_PGOOD is the wired-AND of both converters again.
    The seven symbols are restored verbatim from 48a5f4f rather than rebuilt, so they
    keep their original uuids, and the sheet notes revert with them.
    Everything else round 1 did to power_rails stands, because none of it depended on
    which buck was fitted: the five dual test points, the horizontal 0R links and
    ferrite, the vertical power LED, and no test point on eith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
    [power_rails.kicad_sch]
2026-09-03 review r2 item 2: power_rails PWR_FLAGs moved to their regulators
    They sat in a column of their own in block D, each flag hung off a duplicate
    power symbol that existed only to give it a net. Each now taps the rail it
    declares, on the load side of that rail's 0R link - before the link is a
    different net, so a flag there would declare the wrong thing.
    #PWR346/348/350/352 went with the column: every one of those rails already
    carries a power symbol at its output, so the duplicates declared nothing new.
    Node sets are identical across the change, which is the proof. #FLG301 stays -
    V24_LOGIC arrives at the sheet rather than being made on it, and its flag is
    already beside U301.
    Also fixed, cau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
    [power_rails.kicad_sch]
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2026-09-03 review r2 items 4-7: four per-sheet placement fixes
    4 linear_encoder - U601A's GND body ended at y=166.37 and U601E's +3V3 body
    began at exactly 166.37, so the two flags were touching. The whole U601E
    group drops 7.62 - unit, both flags, four wires, and the no_connect on its
    unused output, which does NOT ride with the symbol: ERC caught that as
    pin_not_connected plus a dangling no-connect the first time round.
    5 temp_sense - C704/C705's grounds sat 0.6 mm above the REFP row with
    TP705's reference on the row itself; the caps and grounds move up 5.08.
    Three verticals ran through the block title, so it is shortened to
    "CHANNEL 2 FILTER + SHARED REF", whi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
    [linear_encoder.kicad_sch, motor_drive.kicad_sch, temp_sense.kicad_sch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]
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2026-09-03 review r3 item 1: a text-clearance checker that sees these, and the sweep
    The captain found two overlaps on power_rails by eye that every previous pass
    had passed: C312's reference against the vertical wire beside it, and U303's own
    value text sitting on its own body's top edge. Both real.
    Four reasons the tooling missed them. The bundled checker grows every field
    rightward from its anchor, so its box is a mirror image whenever text renders
    leftward; it measures text at ~1.06 mm/char where the real advance is ~1.19; it
    never compares a field against its OWN symbol's outline, which is exactly the
    U303 case; and it reports strict overlap only, so text 0.3 mm off a wire passes
    even though both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
    [linear_encoder.kicad_sch, loadcell_afe.kicad_sch, mcu.kicad_sch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]
2026-09-03 review r3 item 2: temp_sense SPI2 hooks become one keyed header, J703
    Five hooks on the SPI2 nets meant five probe leads and five chances to slip a
    clip off a 47R terminator. actuator-rev-afe.md section 7 had already recommended
    this exact part for this exact sheet, so this applies a standing recommendation;
    J502 and J603 are the two existing instances and the channel map copies J603 pin
    for pin - CH0..CH4 on pins 1..5, CH5..CH7 no-connect, GND on 9 and 10. Tapped
    MCU-side of R712..R715 so the bus stays visible with a link out. TP712/TP713
    stay: they are the hooks the analyser's ground leads clip to.
    It reaches its nets by local labels rather than wires - the five arrive at 7.62
    pitch again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
    [temp_sense.kicad_sch]
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2026-09-04 review r3: J902's reference printed through its own value, and the field box bug behind it
    The bundled checker from schematic-style reports 38 findings on the finished
    sheets against this round's 3. Thirty-four are its documented blind spots,
    confirmed against renders - TP702/TP704/TP706's fields are justify right on
    symbols at 180 degrees, which cancel, so the text renders rightward exactly
    where sch_geom puts it; J701/J702's and R705's bodies are reflected about the
    origin because they are mirrored or rotated.
    One was real. J902's reference printed straight through its "SMA Jack" value -
    0.73 mm of overlap, plainly wrong in a render - and this round's checker had
    passed it, because text_b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
    [ui_io.kicad_sch]
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2026-09-04 review r4 items 7,8,13 and the PWR1131 ruling: parts, not placement
    Items 7 and 8, R608 and R609 go. Review round R6 asked for DNP parallel
    positions across R601, FB601 and D601; the captain has reversed two of the
    three, and the reasoning is better than the original: R608 and R601 are the same
    0603, so to meter head current you replace R601 with a shunt rather than
    populate a second footprint beside it, and FB601 can be lifted and bridged
    instead of fitting R609. D602 stays - a second clamp POSITION, for a different
    clamp voltage or a bidirectional part, is not the same argument. Both the sheet
    note and actuator-rev-afe.md's R6 row now carry the reversal rather than
    quietly dropping it.
    It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
    [linear_encoder.kicad_sch, motor_drive.kicad_sch]
2026-09-04 review r4: the captain's two power answers - PG into RAIL_PGOOD, +5V5 to 6 V
    A1. Both ADPL42005 power-good pins join DEC-P9's wired-AND. R317 and R318, 1 k
    each like R315/R316, from each PG down to a local RAIL_PGOOD label - the idiom
    the sheet already uses to reach that node three times. A dead 5 V rail is now
    visible at D303 and TP308, which is the gap round 3 raised.
    A2. +5V5 becomes 6.110 V nominal. The captain asked for 6.0 V - the
    ADPL42005's characterised VIN = VOUT + 1 V point - or slightly above only if the
    tolerance stack needs it to guarantee a 6.0 V minimum. It does: the LMR33630's
    feedback reference is 0.985/1.000/1.015 V, +/-1.5% over the operating range, so
    a 100k/20k divider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
    [motor_drive.kicad_sch, power_rails.kicad_sch]
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2026-09-08 pcb: routing step 1 - the two internal GND planes
    House process step 1: establish the ground planes before any track. Full GND
    fill on In1.Cu and In2.Cu at 0.15 mm minimum width, 0.15 mm clearance, 0.25 mm
    corner fillet, islands always removed, thermal-relief pad connections (G1/G10:
    unbroken, never split).
    Each plane fills as a single outline of 26342 mm^2 -- one continuous pour.
    DRC unchanged at the 19 known library residuals; unconnected drops from 499 to
    499 total but GND's share falls 276 -> 108 as every PTH GND barrel now reaches
    the planes.
    Claude-Session: https://claude.ai/code/session_017ffYKyG4Q48Dk1cCPgUL7k
    [faff2_cbs1.kicad_pcb]
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2026-09-08 pcb: routing step 3b - close the ground-via completeness proof
    Step 3 left C1021 pad 2 with no answer: the PHY's +1V8 decoupler is walled in
    by that rail's own feed on the north and by the USB3320 bias run on the west,
    and step 3's search only ever looks in-line, then swung about the in-line
    axis. Widening it to "any legal via slot within reach, with a maze-routed
    stub" finds one 0.87 mm east-south-east, which no swing was going to reach --
    `tools/route3b_gndfix.py`, run over whatever lands the proof still reports.
    Two proofs corrected to measure the physical thing rather than a proxy:
    * via-in-pad was flagging any via whose *copper* touched a pad, so 24
    same-net G1d hugs read as de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
    [faff2_cbs1.kicad_pcb]
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2026-09-09 pcb: routing step 5 wip - fanout lanes and commutation pass A (inherited)
    Banks the previous session's uncommitted step-5 progress before any further
    edit, so the work is not lost: 638 segments and 88 vias on top of 9559620,
    unconnected 390 -> 267.
    Known defect carried in with it, fixed next: the USB HS pair reaches J1001
    with DM and DP crossed over each other's pads, giving 9 shorting_items,
    2 tracks_crossing, 3 clearance and 2 solder_mask_bridge violations, all
    inside the 3 mm in front of the connector. Everything else DRC-clean beyond
    the in-progress dangling stubs.
    Claude-Session: https://claude.ai/code/session_01WqUrajr7x5bwUMvjXpV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
    [faff2_cbs1.kicad_pcb]
2026-09-09 pcb: routing step 5a - the USB HS pair, drawn rather than routed
    Step 5 let the maze router loose on USB_DM/USB_DP. With two pads per net in
    one 0.5 mm row it treated them as interchangeable and ran DM along the pad
    row through A6, a DP pad: nine shorting_items, two tracks_crossing, three
    clearance and two solder_mask_bridge violations, all inside 3 mm of J1001.
    A differential pair is a geometry specification, not a connectivity problem,
    so tools/route9_usb.py draws it: explicit polylines, mirror images about
    x = 150.0 wherever the two run together, so the match is by construction.
    0.30 mm wide on 0.20 mm gap over In1.Cu = 90.6 ohm, F.Cu the whole through
    path, no vias in either half. Thr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
    [faff2_cbs1.kicad_pcb]
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2026-09-09 pcb: routing step 5b - the DRV8323 interface, accuracy before length
    tools/route8_drv.py, run. Fourteen nets have to reach one 6 mm package from
    three legs spread over 30 mm, through a channel that also carries the motor
    bus and the driver's own supply, and step 5's leg-by-leg order gave the
    channel to whichever net asked first. This rips the window and redoes it in
    priority order.
    Priority is accuracy, not length: the three Kelvin taps go first. Each has
    exactly one useful path -- from the shunt's own pad, never the power path --
    and the CSA's gain error is whatever IR drop the tap picks up. A gate run
    that detours 4 mm costs nanoseconds of edge; a Kelvin tap that detours costs
    percent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
    [faff2_cbs1.kicad_pcb]
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2026-09-09 pcb: routing step 5c, and the two sealed pins
    Step 5c -- route5_critical.py --stages rs422,analog,rf,clocks, one process per
    stage -- ran and banked, and it moved the board by 31 tracks and 3 vias and
    not one net. That is the finding, not a disappointment: the RS-422 pairs, the
    USB crystal pair, SYNC_TRIG and ADS1235_CLKIN are each split at exactly one
    pin, and those pins are sealed.
    Two pins were walled in by earlier steps, and both are the R3-1 hazard the
    house rules name -- a net drawn across a pin ring before the pins in it were
    routed. Neither is fixed by retrying harder; a sealed pin has no lane at any
    width on either layer. Both are fixed by resequencing.
    route_ripup.py gains the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
    [faff2_cbs1.kicad_pcb]
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2026-09-09 pcb: routing step 5e - free the USB crystal pins; AGENTS.md routing section
    route11_sealed.py, run. C1020's ground stitch escaped due south, which is the
    only corridor U1002 pins 25/26 have, so the stitch swings north-west into open
    board and the crystal pair takes the lane. USB_XO_24M came whole immediately;
    USB_REFCLK_24M is left for the general fill. Unconnected 254 -> 247.
    AGENTS.md gains a Routing phase section and the stale G7 line is corrected --
    the gate is cleared and the board is no longer at 0 tracks. What is worth
    every future session's time: run DRC with AMODO_KICAD_LIB set or it reports
    199 phantom lib_footprint_issues and buries the six real mismatches; the
    recurring fail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
    [faff2_cbs1.kicad_pcb]
2026-09-09 pcb: route12_sync - put the sync clamp back at the head of the line
    Net-(D903-K) came out of step 5c connected but not in the house order. The
    run leaves J902 pin 1 heading for D903 and R907 taps it at (88.70, 41.35) --
    5.6 mm along, clamp still 4.5 mm further on -- so a strike reaches the branch,
    divides, and part of it is on its way to U901 before meeting the clamp at all.
    The rule is source pad, clamp pad, then the series element, in series, and the
    fix is the ordering rather than the copper.
    It cannot fix the other half of the problem, which is placement: D903 sits
    9.4 mm of trace from the SMA pin it protects, where the house rule wants the
    neighbouring courtyard. Logged as an open po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
    [route12_sync.py]
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2026-09-09 pcb: unseal the +6V0 supply pins; the DRV east row is a placement finding
    The u302-pg and u303-pg plans now put +6V0 back whole on both regulators --
    the pins route14_sealed named as sealed are free. PGOOD is split on both,
    which is the same trade in the other direction; the next run biases +6V0's
    tie under the ring so both can have their lane.
    The three low-side gates and VM_DRV are still open, and that is now a
    measured claim rather than a failed search. DRV8323 pins 5..9 -- V24_MOT,
    Q1101-G, MOTOR_U, Q1102-G, Q1102-S_3 -- all leave eastward on a 0.5 mm pitch
    and all turn off inside the same 1.5 mm of board. A lane between two
    neighbouring runs is 0.70 mm; a 0.6 mm via needs 0.905 mm t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
    [faff2_cbs1.kicad_pcb]
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
